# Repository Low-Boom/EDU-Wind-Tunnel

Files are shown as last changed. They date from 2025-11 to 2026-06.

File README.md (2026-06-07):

# Educational Wind Tunnel Controller
**Microcontroller-based PID controller for educational wind tunnel systems**

Developed by [Louis M. Edelman](https://www.researchgate.net/profile/Louis-Edelman) and Olivia Coulon

Debugging assitance provided by Antropic Claude Sonnet 4.5 and verified by humans.

Developed for use with the [Modular Wind Tunnel for STEM Education](https://www.printables.com/@JerrodH) by [Jerrod Hofferth](https://jerrod.hofferth.net/)















---

## Features

### Control & Tuning
- **Full PID Control** (Proportional, Integral, Derivative)
- **Relay Auto-Tuning** (Åström-Hägglund method)
- **sTune Auto-Tuning** (Inflection Point method - optional advanced tuning)
- **Manual PID Tuning** (direct gain adjustment)
- **PWM Rate Limiting** (smooth motor transitions)

### Sensor Processing
- **Pressure Oversampling** (noise reduction)
- **Configurable Airspeed Averaging** (default 20)
- **Ambient Temperature Compensation** (automatic air density correction)
- **Zero-Offset Calibration** (automatic at startup, manual recalibration at will)
- **Multi-Bus I2C Scanner** (automatic device discovery on all available I2C buses)

### Features in Development (Eventually) 
- Serial free untethered control via Modulino controls and a screen for mobility
- A [Controllino](https://www.controllino.com) PLC-based version for industrial applications and education
- A [Mathworks Simulink](https://www.mathworks.com/products/simulink.html) and [Julia Hub DYAD](https://juliahub.com/products/dyad) compatible controller
- Integrated Lift-Drag Force Balance
- Coursework materials for wind tunnel operation and design

---
## Detailed Documentation

- **[HARDWARE.md](HARDWARE.md)** - Detailed wiring, components, and power supply info
- **[TUNING_GUIDE.md](TUNING_GUIDE.md)** - Advanced PID tuning techniques
---

## Quick Start

### Prerequisites
- Arduino IDE 2.0+ or [VSCode with PlatformIO](https://platformio.org/install/ide?install=vscode) (see Installation notes)
- ESP32-P4 microcontroller board (primary/recommended; see [HARDWARE.md](HARDWARE.md) for all supported boards)
- DFRobot SEN0343 (Fermion LWLP5000) differential pressure sensor (±500 Pa, I2C)
- DFRobot SEN0665 (Fermion BMP585) barometric pressure/temperature sensor (I2C)
- PWM-controlled fan with external power source (e.g.[ AC Infinity CLOUDLINE A8 EC-PWM Motor](https://acinfinity.com/hydroponics-growers/cloudline-a8-quiet-inline-fan-with-speed-controller-8-inch/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) or [Noctua 12V PC Fan](https://www.noctua.at/en/products/nf-a14x25-g2-pwm) as recommended by Jerrod H.)
- Depending on board and fan combination, a [Bi-Directional Logic Level Lifter](https://www.adafruit.com/product/757?srsltid=AfmBOopBWeXgpfL63fDoCPbWWtu07TIO7QVbofNmTDtQ4QkU7BxYeCWk) with at least two channels
---

## Hardware Setup

⚠️ Motor power supply must be separate from the microcontroller! This is 120V AC Power for the AC Infinity Fan or a 12V power supply for the 12V PC Fan (e.g. [Noctua NV-PS1](https://www.noctua.at/en/products/nv-ps1))

See [HARDWARE.md](HARDWARE.md) for detailed wiring diagrams and component specifications.

---

## ⚠️ Safety Warnings

1. **Motor Power**: NEVER power motor from the microcontroller - use separate supply
2. **Mechanical**: Secure all components, keep clear of fan during operation
3. **Testing**: Start with low speeds (2-5 m/s), gradually increase
4. **Emergency**: Type `0` to stop or disconnect motor/fan from power

---

### Installation

1. **Install IDE**
   - **Arduino IDE** (recommended for beginners): Download from https://www.arduino.cc/en/software
   - **VSCode + PlatformIO** (alternative, recommended for advanced users): Install [VSCode](https://code.visualstudio.com/) then add the [PlatformIO IDE extension](https://platformio.org/install/ide?install=vscode). PlatformIO handles board packages and libraries automatically.

2. **Install Board Support** (Arduino IDE only; PlatformIO manages this automatically)
   - Open: Tools → Board → Boards Manager
   - Search: "esp32 by Espressif Systems" and install version **3.x** (required for ESP32-P4)
     - Select "ESP32P4 Dev Module" for ESP32-P4 boards (e.g. [Waveshare ESP32-P4-WiFi6-Touch-LCD-7B](https://www.waveshare.com/product/arduino/boards-kits/esp32-p4/esp32-p4-wifi6-touch-lcd-7b.htm))
     - M5 Atom users: version 2.0+ is sufficient; additionally install the [M5Stack board package](https://docs.m5stack.com/en/arduino/arduino_board) or select a generic ESP32 board and configure `PlatformConfig.h` manually
   - For Arduino/Mbed boards: search for the appropriate Mbed OS board package (e.g. "Arduino Mbed OS Giga Boards")

3. **Install Required Libraries**
   - Open: Tools → Manage Libraries
   - Install:
     - `DFRobot_BMP58X` (for DFRobot SEN0665 barometer) — also requires `DFRobot_RTU`
     - `DFRobot_LWLP` (for DFRobot SEN0343 differential pressure sensor)
     - QuickPID
     - **sTune** (optional - for advanced PID autotuning)

4. **Upload Code**
   - Open `EDU-Wind-Tunnel.ino`
   - Select Board: "ESP32P4 Dev Module" (or your specific board)
   - Select Port: Your board's COM port
   - Click Upload

5. **Open Serial Monitor**
   - Set baud rate: **115200**
   - Watch initialization messages to confirm successful hardware setup. 

6. **Allow for Initial Calibration"
   - Once the fan is under control, it will ramp down to 0.
   - A default wait time of 30 seconds is set to allow for the airflow in the tunnel to fully stop
   - 50 Samples are taken from the airspeed sensor to establish a zero offset.
   - This routine can be re-run via the `recal` serial command later

---

## Quick Command Reference

| Command | Description | Example |
|---|---|---|
| `<number>` | Set target airspeed | `10` |
| `tune` | Auto-tune (auto PWM) | `tune` |
| `tune <L> <H>` | Auto-tune (manual PWM) | `tune 40 100` |
| `tune <Kp> <Ki> <Kd>` | Manual PID | `tune 20 8 12` |
| `stune` | sTune auto-tune (advanced) | `stune` |
| `recal` | Recalibrate sensor | `recal` |
| `recal <N>` | Recalibrate (N samples) | `recal 100` |
| `avg <N>` | Set averaging | `avg 10` |

## User-configurable variables (runtime & compile-time) 

### Runtime Commands (via serial)
- Direct setpoint: type a number (m/s) to set target.
- `avg <N>`  
  - Purpose: set pressure averaging samples (1–50). Default 20.  
  - Effect: lower → faster but noisier; higher → smoother but more lag.  
  - Typical: `avg 3` for fast tuning, `avg 15–30` for stable operation.

- `tune` / `tune <low> <high>` / `tune <Kp> <Ki> <Kd>`  
  - `tune` : auto-estimate PWM band and run relay tuning.  
  - `tune <low> <high>` : force PWM range (manual). Use when auto-estimate is poor.  
  - `tune <Kp> <Ki> <Kd>` : manually apply PID gains; controller resets automatically.

- `stune` (requires sTune library)
  - Advanced autotuning using inflection point method
  - More stable and predictable than relay tuning
  - Automatically determines step size and monitors system response
  - Default: "No Overshoot" tuning for stable operation
  - Usage: Set target airspeed (min 2 m/s), then type `stune`
  - Duration: ~30-60 seconds depending on system response
  - **Tuning method can be changed** at compile-time (see below)

### Compile-time (edit `EDU-Wind-Tunnel.ino`)
Open the sketch and edit the configuration block near the top:

- **`PlatformConfig.h`** – controls all board-specific pin defaults.  Edit this
  file if your wiring differs from the defaults:
  - M5 Atom Stack: `DEFAULT_PWM_PIN 19`, `DEFAULT_TACH_PIN 23`, I2C on GPIO 26/32 (Grove)
  - Generic ESP32-S3: `DEFAULT_PWM_PIN 10`, `DEFAULT_TACH_PIN 11`, I2C on GPIO 8/9
  - ESP32-P4 (Waveshare): `DEFAULT_PWM_PIN 6`, `DEFAULT_TACH_PIN 5`, I2C on GPIO 7/8
  - Generic ESP32: `DEFAULT_PWM_PIN 9`, `DEFAULT_TACH_PIN 2`, I2C on GPIO 21/22
  - Classic Arduino: `DEFAULT_PWM_PIN 9`, `DEFAULT_TACH_PIN 2` (board defaults)

- `const sTune::TuningMethod STUNE_METHOD = sTune::NoOvershoot_PID;`
  - Selects the sTune tuning method (default: NoOvershoot_PID for stability)
  - Available options:
    - `sTune::ZN_PID` - Ziegler-Nichols (moderate overshoot, fast response)
    - `sTune::DampedOsc_PID` - Damped Oscillation (balanced)
    - `sTune::NoOvershoot_PID` - No Overshoot (conservative, stable) **[DEFAULT]**
    - `sTune::CohenCoon_PID` - Cohen-Coon (good for systems with delay)
    - `sTune::Mixed_PID` - Mixed (average of all methods)
  - For PI control instead of PID: use ZN_PI, DampedOsc_PI, NoOvershoot_PI, etc.

- `const int PRESSURE_OVERSAMPLES = 5;`  
  - Oversampling per measurement (3–8 typical).

- `int pressureAverageSamples = 20;`  
  - Averaging window for measurements (1–50). Effective lag ≈ updateInterval × pressureAverageSamples.

- `const unsigned long updateInterval = 200;`  
  - Main loop period in ms (default 200 ms). If changed, QuickPID sample time will be set from this.

- `int calibrationSamples = 50;`  
  - Samples used for zero-offset calibration at startup/recal.

- `const float MAX_AIRSPEED = 28.0;`  
  - Upper bound for setpoints; change if your tunnel differs.

- `const float MAX_PWM_CHANGE_PER_CYCLE = 25.0;`  
  - PWM slew limit per update cycle; set to 255 to disable.

- `float relayHysteresis = 0.5;`  
  - m/s hysteresis for relay auto-tune to prevent chattering.

- `const int PWM_pin = 9;` and `const int TACH_pin = 2;`  
  - Pin assignments; change if wiring differs.

- `const float MIN_TUNE_SETPOINT = 2.0;` and `const int REQUIRED_CYCLES = 3;`  
  - Minimum auto-tune setpoint and cycles needed for a valid tune.

Data output format
These can be quickly plotted using the Arduino IDE Serial Plotter or logged for later processing in a .csv format.
Example line printed periodically:
```
123s | V:10.23 | T:10.00 | PWM:127 | P:61.45 | T:24.5°C | Err:-0.23

elapsed time | airspeed (m/s) | target (m/s) | PWM (0–255) | differential pressure (Pa) | ambient temp (°C) | error (m/s)
```
---

## Serial Control from Android

Once the sketch is compiled and uploaded, it can be controlled via a USB connection to an Android phone using the excellent [Serial USB Terminal App by Kair Morichi](https://www.kai-morich.de/android/).

1. Connect via a USB cable with whatever adapters or USB-C hubs are required for your particular phone and board.

2. Set the Baud Rate to 115200 and operate as you would from the Arduino IDE

3. It is recommended that you set macros in the app according to the Quick Command Reference table above.

---

## I2C Device Scanner

The system includes an automatic I2C device scanner that runs at startup to help verify sensor connections. The scanner automatically detects and scans all available I2C buses on your board:

- **ESP32 / ESP32-S3 / ESP32-P4 / ESP32-PICO (M5 Atom)**: Scans Wire only; Wire is initialised with the SDA/SCL pins defined in `PlatformConfig.h`
- **Classic Arduino (Uno, Nano, Mega)**: Scans Wire only
- **Arduino Uno Rev4**: Scans Wire and Wire1
- **Modern Boards (RP2040, SAMD21/51)**: Scans Wire and Wire1
- **Arduino GIGA R1**: Scans Wire, Wire1, and Wire2

### Expected Output

On successful startup, you should see:
```
[I2C] Multi-Bus Scanner
=====================================
Available I2C buses: 2
Scanning I2C bus Wire
 - Found device at 0x47
 - Total devices found on Wire: 1

Scanning I2C bus Wire1
 - No I2C devices found on Wire1

[I2C] Scan complete
=====================================
```

The DFRobot SEN0665 (BMP585) barometer should appear at address `0x47` (or `0x46` if the address jumper is changed).
The DFRobot SEN0343 (LWLP5000) differential pressure sensor uses I2C address `0x00` (a fixed hardware address) and will **not** appear in the bus scan — it is initialised directly and its absence from the scan is expected and normal.

If the BMP585 is not found, check:
- I2C wiring (SDA/SCL connections)
- Device power supply (3.3 V)
- Pull-up resistors (typically built into breakout boards)

---

## 📄 License
Derived from the Modular Wind Tunnel for STEM Education by Jerrod H. under a Creative Commons4.0 License

This project uses open-source libraries:
- QuickPID (MIT License)
- DFRobot_BMP58X (MIT License) — for DFRobot SEN0665 (BMP585 barometer)
- DFRobot_LWLP (MIT License) — for DFRobot SEN0343 (LWLP5000 differential pressure sensor)
- sTune (MIT License) - Optional advanced autotuning library by David Lloyd

See individual library licenses for details.

---

## Support
This code is provided with no warranty or expectation of support. If you post something in the issues or discussion sections of GitHub I or another community member may be able to resolve your question. 
This is an initial release so the documentation and best practices are still evolving. If you have contributions, please fork, tweak, pull, and merge at your discretion.

- **Issues**: [GitHub Issues](https://github.com/Low-Boom/EDU-wind-tunnel/issues)
- **Discussions**: [GitHub Discussions](https://github.com/Low-Boom/EDU-wind-tunnel/discussions)

---

## Acknowledgments
- Jerrod H. for the Wind Tunnel Design
- QuickPID Library by Dlloydev
- sTune Library by Dlloydev
- DFRobot for the BMP58X (SEN0665) and LWLP (SEN0343) sensor libraries
- Arduino and Espressif communities for board and library support

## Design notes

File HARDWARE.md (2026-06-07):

# Hardware Configuration Guide

## Hardware Modifications to Educational Wind Tunnel
A static pressure ring must be added at the inlet of the test section to measure airspeed.
An updatead version of the test section or an additional component between the inlet and test section are included for this purpose. Get them from [Printables](https://www.printables.com/model/1480487-airspeed-static-pressure-ring-modification-for-edu).

## Required Components

- A compatible microcontroller
	- **ESP32-P4 (Recommended)**
   		- [Waveshare ESP32-P4-WiFi6-Touch-LCD-7B](https://www.waveshare.com/product/arduino/boards-kits/esp32-p4/esp32-p4-wifi6-touch-lcd-7b.htm), [M5Stack Tab5 P4 Board](https://shop.m5stack.com/products/m5stack-tab5-iot-development-kit-esp32-p4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), or other ESP32-P4 dev-boards
	          - Dual-core RISC-V; WiFi 6 via on-board ESP32-C6 companion chip; requires ESP32 Arduino core 3.x
	- Other supported ESP32 boards
	     - [M5 Atom Lite / M5 Atom Stack (ESP32-PICO-D4)](https://shop.m5stack.com/products/atom-lite-esp32-development-kit)  (requires ESP32 Arduino core 2.0+)
	          - Compact form-factor; sensors attach to the Grove/HY2.0 bottom connector
	     - Generic ESP32-S3 dev-boards  (requires ESP32 Arduino core 2.0+)
	     - Any generic ESP32 board (WROOM, WROVER, etc.)
	- Arduino or Arduino Compatible MBED microcontroller (alternative/legacy)
	     - [Arduino Uno Rev. 4](https://store-usa.arduino.cc/pages/uno-r4?srsltid=AfmBOorOs0ix30CZM4vLKSA9m6F7qrPhlblCfdp3-wQMstfBhTvr8o13)
	     - [Arduino Mega 2560 Rev. 3](https://store-usa.arduino.cc/products/arduino-mega-2560-rev3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)
	     - [Arduino Giga R1/R1 Wifi](https://store-usa.arduino.cc/products/giga-r1-wifi?queryID=a518cc78eda98ff33faf6b976f3d470a)
- [3D Printed Educational Wind Tunnel with Static Pressure Ring](https://www.printables.com/model/1480487-airspeed-static-pressure-ring-modification-for-edu) Modification
- [Static Pressure Manifold](https://www.printables.com/model/1480487-airspeed-static-pressure-ring-modification-for-edu)
     - 3D Printed Manifold for 4x 0.063in (1/16in) to 1x 0..125in (1/8in) tubing
     - [Scanivalve Pneumatic Manifolds](https://scanivalve.com/products/pneumatic-connectors-and-tubing/pneumatic-manifolds/)
- DFRobot SEN0343 (Fermion LWLP5000) differential pressure sensor (±500 Pa, I2C address 0x00)
- DFRobot SEN0665 (Fermion BMP585) barometric sensor (I2C address 0x47, alt 0x46)
- PWM-capable motor or fan
     - For Standard 140 mm Wind Tunnel: [Noctua NF-A12x25 G2 PWM](https://www.noctua.at/en/products/nf-a12x25-g2-pwm) with a Noctua [NV-PS1](https://www.noctua.at/en/products/nv-ps1) or [NV-SPH1](https://www.noctua.at/en/products/nv-sph1) Power Supply or similar with the 
     - For Larger 8in/200mm Fann Driven Tunnel: [AC Infinity CLOUDLINE A8, Quiet Inline Fan with Speed Controller](https://acinfinity.com/hydroponics-growers/cloudline-a8-quiet-inline-fan-with-speed-controller-8-inch/)
          - Note DO NOT get the "smart" version. The standard PWM speed controller version is needed here.
          - The now depracated but still available [AC Infinity CLOUDLINE S8 Pro](https://a.co/d/iekl0lr) is an equivalent option
- Four Pin PWM Fan Cable such as the [Noctua NA-SEC1](https://www.noctua.at/en/products/na-sec1)
- 1/16 in (0.063in) OD steel tubing for static pressure taps
     - [McMaster 304 Stainless Steel Tubing Miniature, 0.065" OD, 0.009" Wall Thickness](https://www.mcmaster.com/5560K73-5560K731/)
     - [063 Scanivalve Stainless Steel Tubulations](https://scanivalve.com/products/pneumatic-connectors-and-tubing/stainless-steel-tubulations/)
     - [Amazon 304 Stainless Steel Capillary Tube, OD 1.5mm](https://a.co/d/c9E1Kos)
- 1/16in (0.063in) ID soft line silicone or polyurethane/Tygon tubing
     - [Scanivalve 063 Plastic Tubing](https://scanivalve.com/products/pneumatic-connectors-and-tubing/plastic-tubing/)
     - [Amazon 1/16" ID Silicone Tubing, Food Grade 1/16" ID x 1/8" OD 10 Feet Length Pure Silicone Hoses](https://a.co/d/4P2acrw)
- 1/8in (0.125in) ID soft line silicone or polyurethane/Tygon tubing
     - [Scanivalve 125 Plastic Tubing](https://scanivalve.com/products/pneumatic-connectors-and-tubing/plastic-tubing/)
     - [Amazon 1/8" ID Silicone Tubing, Food Grade 1/8" ID x 3/16" OD 10 Feet Length Pure Silicone](https://a.co/d/5y4ox0C)
- Assorted STEMMA QT/Qwiic 4-pin I2C Cabling. At least three (3) QT to QT and one QT to Female Dupont Sockets are recommended. Extras are always a good idea
     - [Adafruit Qwiic Cabling](https://www.adafruit.com/product/4399)
     - [Amazon I2C Qwiic Cable Kit Assortment](https://a.co/d/anmSIUS)
- One STEMA QT/Qwiic to JST-GH Adapter for the airspeed sensor
     - You can make one yourself by splicing the airspeed sensors included cable with a Qwiic
     - [Aamazon GH Connector to Dupont 2.54 Adapter Kit](https://a.co/d/dRP7Vl2)

---

## ESP32 Pin Mapping

All ESP32 pin defaults are set in `EDU-Wind-Tunnel/PlatformConfig.h`.
Edit that file if your wiring differs.

### ESP32-P4 (e.g. Waveshare ESP32-P4-WiFi6-Touch-LCD-7B) — Recommended

| Function | GPIO | Notes |
|---|---|---|
| Serial | USB  | 115200 baud via USB |
| PWM output | 6  | Use GPIOs ≤ 36 (change as needed) |
| Tachometer | 5  | Use GPIOs ≤ 36 (change as needed) |
| I2C SDA | 7  | ESP32-P4 default |
| I2C SCL | 8  | ESP32-P4 default |

> **ESP32-P4 notes** – The ESP32-P4 is a dual-core RISC-V chip without built-in
> WiFi/BT; the Waveshare board pairs it with an ESP32-C6 for WiFi 6.  GPIOs 14-19
> are reserved for the SDIO host interface to that companion chip — do not
> reassign them.  Use GPIOs ≤ 36 to avoid LDO power issues on higher-numbered
> pins.  Requires ESP32 Arduino core **3.x** (select "ESP32P4 Dev Module" in the
> board manager).

### M5 Atom Stack / M5 Atom Lite (ESP32-PICO-D4)

| Function | GPIO | Notes |
|---|---|---|
| Serial | USB  | 115200 baud via USB-C |
| PWM output |  19  | HAT header or breadboard (change as needed) |
| Tachometer |  23  | HAT header or breadboard (change as needed) |
| I2C SDA |  26  | Grove / HY2.0 bottom connector |
| I2C SCL |  32  | Grove / HY2.0 bottom connector |

> **Note** – Both the DFRobot SEN0665 (BMP585) barometer and the DFRobot SEN0343
> (LWLP5000) differential pressure sensor operate at 3.3 V and are compatible
> with the Grove connector's 3.3 V power rail.

### Generic ESP32-S3

| Function | GPIO | Notes |
|---|---|---|
| Serial | USB  | 115200 baud via USB |
| PWM output |  10  | Any PWM-capable GPIO (change as needed) |
| Tachometer |  11  | Any interrupt-capable GPIO (change as needed) |
| I2C SDA | 8  | Standard ESP32-S3 dev-board default |
| I2C SCL | 9  | Standard ESP32-S3 dev-board default |

### Generic ESP32

| Function | GPIO | Notes |
|---|---|---|
| Serial | USB  | 115200 baud |
| PWM output | 9  | Any PWM-capable GPIO |
| Tachometer | 2  | Any interrupt-capable GPIO |
| I2C SDA |  21  | Standard ESP32 default |
| I2C SCL |  22  | Standard ESP32 default |

> **PWM note** – `analogWrite()` on ESP32 (core 2.x+) generates ~1 kHz PWM at
> 8-bit resolution (0–255), which should be compatible with most fans.  Fans that
> strictly require a 25 kHz signal may need an additional LEDC configuration
> (see Arduino ESP32 `ledcWrite` documentation).

## Arduino / Mbed Pin Mapping (alternative/legacy boards)

- Serial: USB / Serial Monitor at 115200 baud
- PWM output: Arduino digital pin 9 → PWM signal input
- PWM Tachometer input: Arduino digital pin 2 (optional)
- I2C: SDA / SCL → BMP585 (SEN0665) and LWLP5000 (SEN0343)
     - Automatic I2C bus detection for BMP585 (e.g. Wire, Wire1, Wire2).
     - LWLP5000 always uses the primary Wire bus (I2C address 0x00 is fixed).
     - Sensors can be used on the same or different buses
	- BMP585 Barometer supports 3.3V power.
	- LWLP5000 Differential Pressure Sensor supports 3.3V power.
 	- See I2C section below for more detail on wiring configuration alternatives

## If Using the AC Infinity PWM Fans (Skip if Using 12V PC Fan)

AC Infinity uses an industrial 10V PWM standard while most microcontroller boards output 3.3V or 5V PWM logic. You will need to interpose a bi-directional level logic shifter to ensure the AC Infinity blower runs at full performance.

The [Adafruit 4-channel Bi-Directional Logic Level Converter - BS138](https://www.adafruit.com/product/757) is recommended for this. For more information on PWM wiring standards, read the [PWM White Paper by Noctua](https://cdn.noctua.at/media/Noctua_PWM_specifications_white_paper.pdf).

Note that many third-party Arduino-based boards have different Vin limits than first-party Arudino boards. For example, Adafruit Metro boards max out at 9V. As such, do not power the microcontroller directly from the fan unless you know your particular board can handle 10 Vin. Skip the 10V power connections and use USB power for such boards.

The wiring configration for control logic and sensors for the Arduino Mega 2560, Giga R1, and Uno R4 with an AC Infinity fan are diagramed below. 

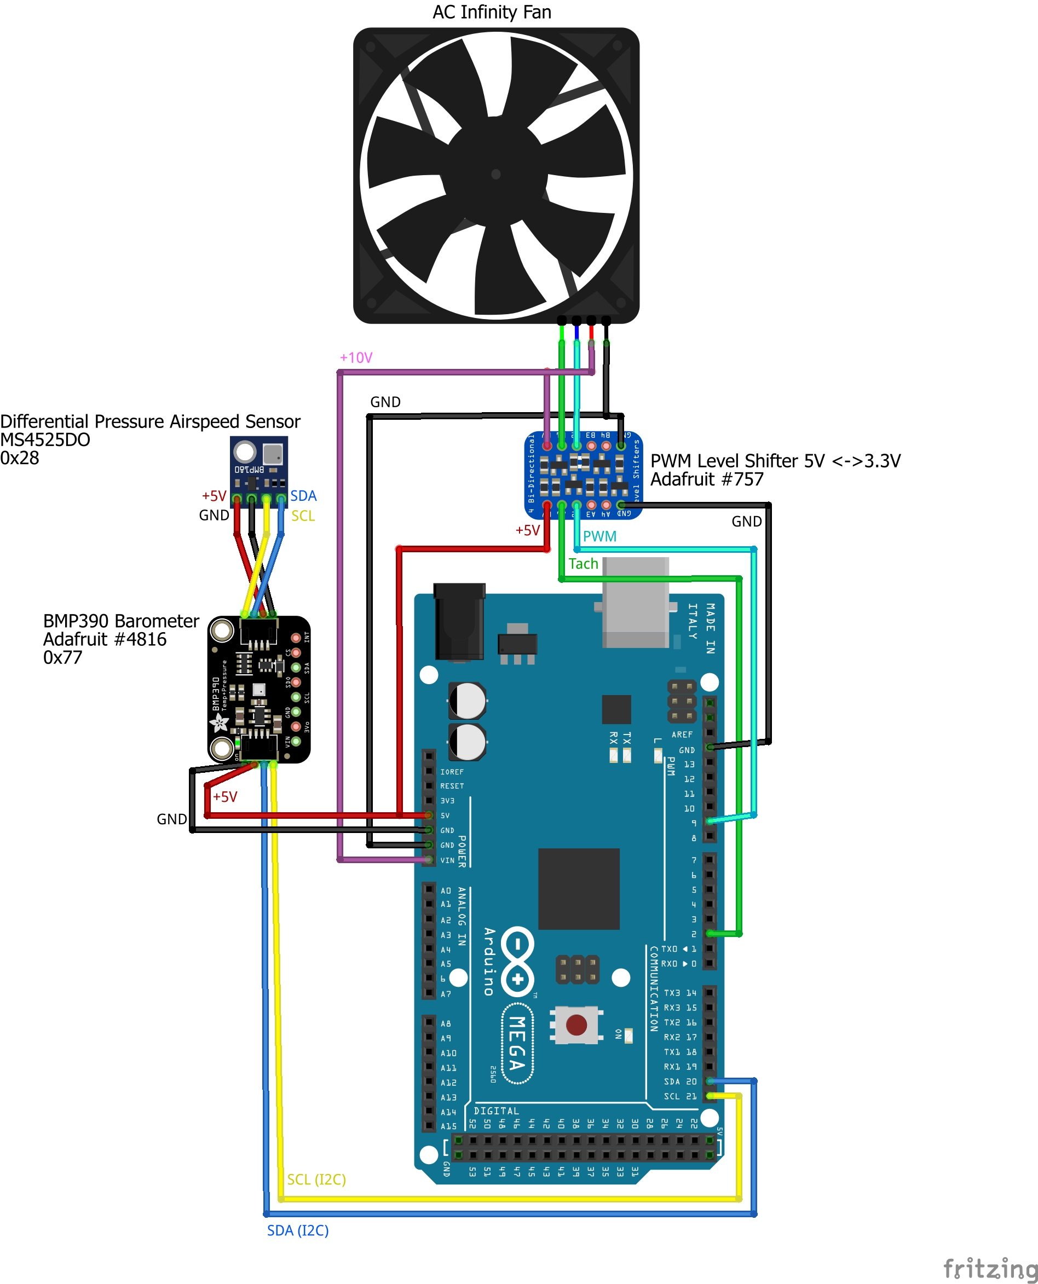
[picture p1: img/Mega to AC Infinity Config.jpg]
Arduino Mega 2560 and AC Infinity Fan Wiring Configration
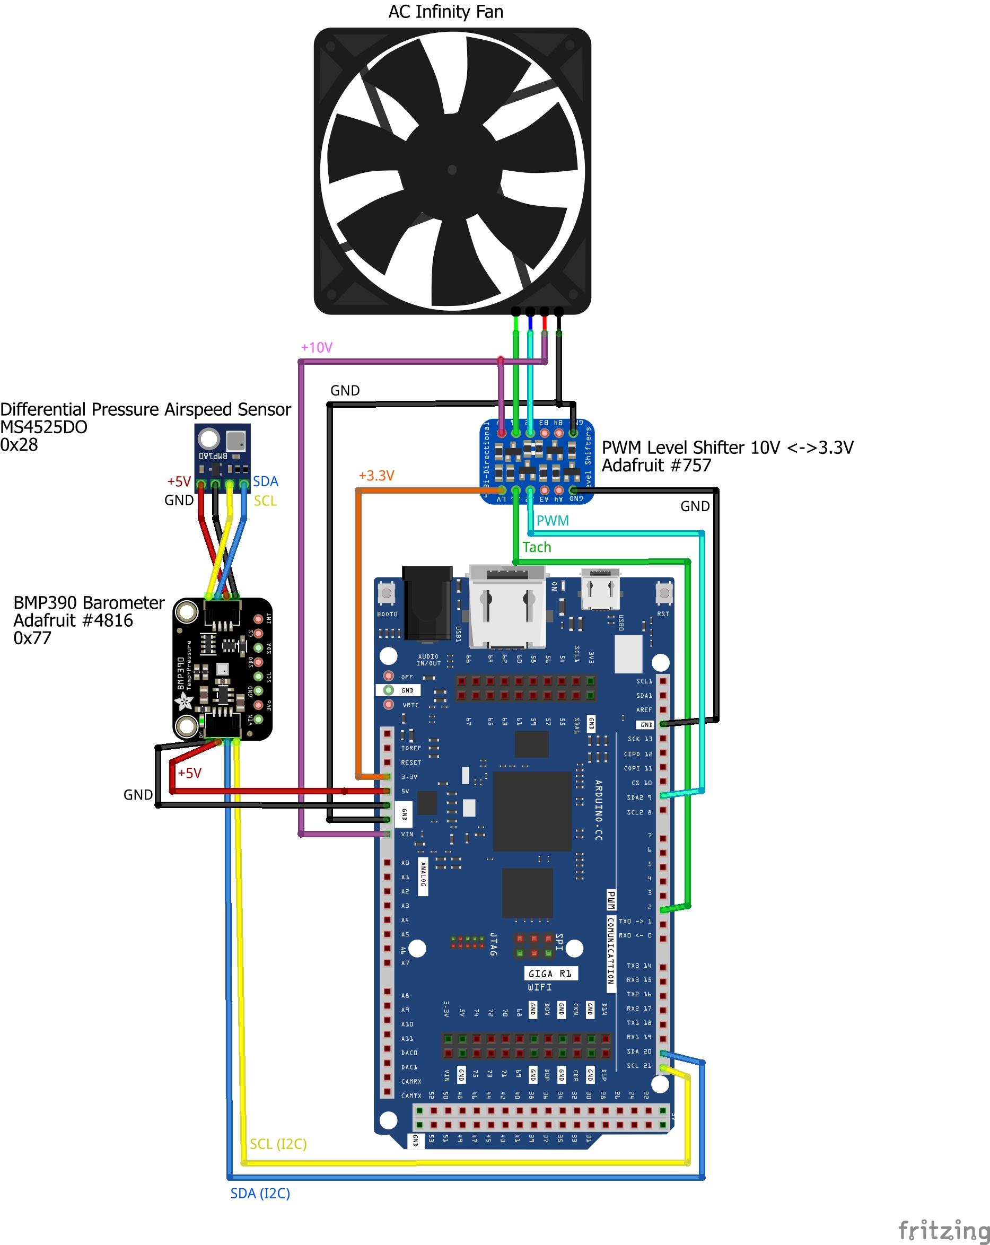
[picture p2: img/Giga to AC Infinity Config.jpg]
Arduino Giga R1 and AC Infinity Fan Wiring Configration
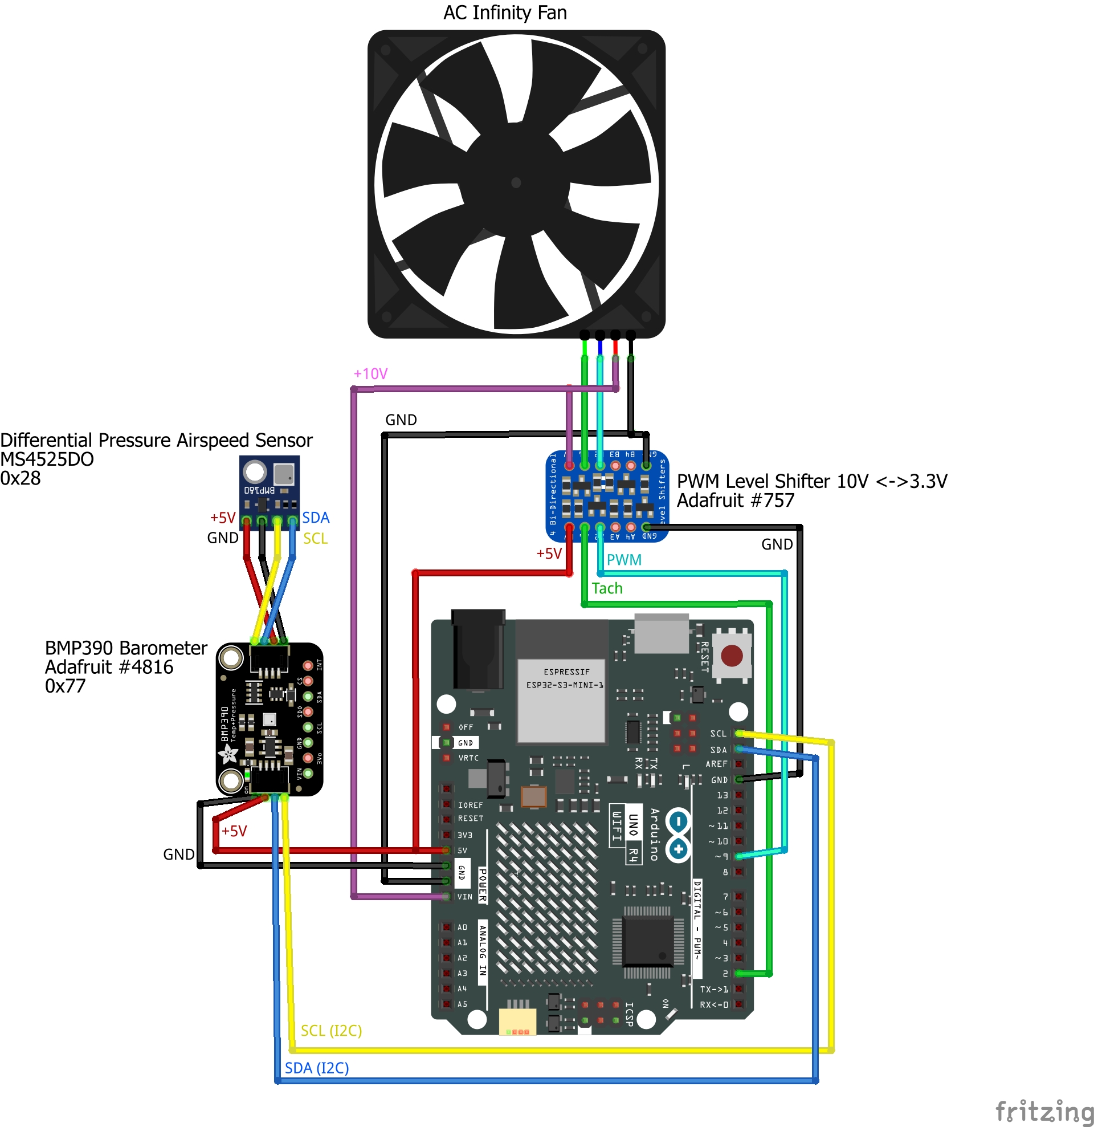
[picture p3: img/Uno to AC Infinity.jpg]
Arduino Uno R4 and AC Infinity Fan Wiring Configration
 

Additionally. You should wire a standard 4-pin fan connector, such as the [Noctua NA-SEC1](https://www.noctua.at/en/products/na-sec1), in place of the AC Infinity UIS USB-C(ish) connector. Connect a corresponding female 4-pin connector to your logic level board. These can be created quickly using a single 4-pin fan extension cabling and a little crimping.

Unscrew the four self tapping screws that secure hatch on the side of the AC Infinity fan to reveal the wiring terminal block. Wire it as noted in the image below. TAC is the fan tachometer feedback, PWM is the control signal. 

> Note: Some newer AC Infinity models seem to have removed the terminal block pictured however wire color coding appears to be identical. It is recommended that you add in your own terminal block for convenience.
     
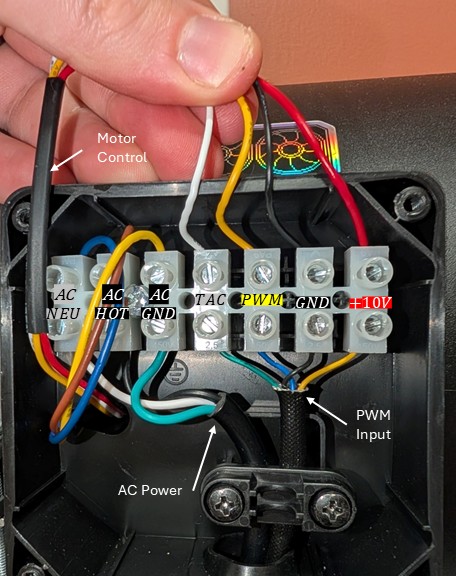
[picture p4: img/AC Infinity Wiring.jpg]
AC Infinity Terminal Block Wiring
 

## If Using a 12V PC Fan (Skip if Using AC Infinity Fan)

PC fans use the 5V PWM standard as outlined in the [PWM White Paper by Noctua](https://cdn.noctua.at/media/Noctua_PWM_specifications_white_paper.pdf). Most ESP32 boards output 3.3V logic, so you will need to interpose a bi-directional level logic shifter to ensure full performance.

The [Adafruit 4-channel Bi-Directional Logic Level Converter - BS138](https://www.adafruit.com/product/757) is recommended for this.

The wiring configration for control logic and sensors for the Arduino Mega 2560, Giga R1, and Uno R4 with an externally powered 12V PC Fan are diagramed below.

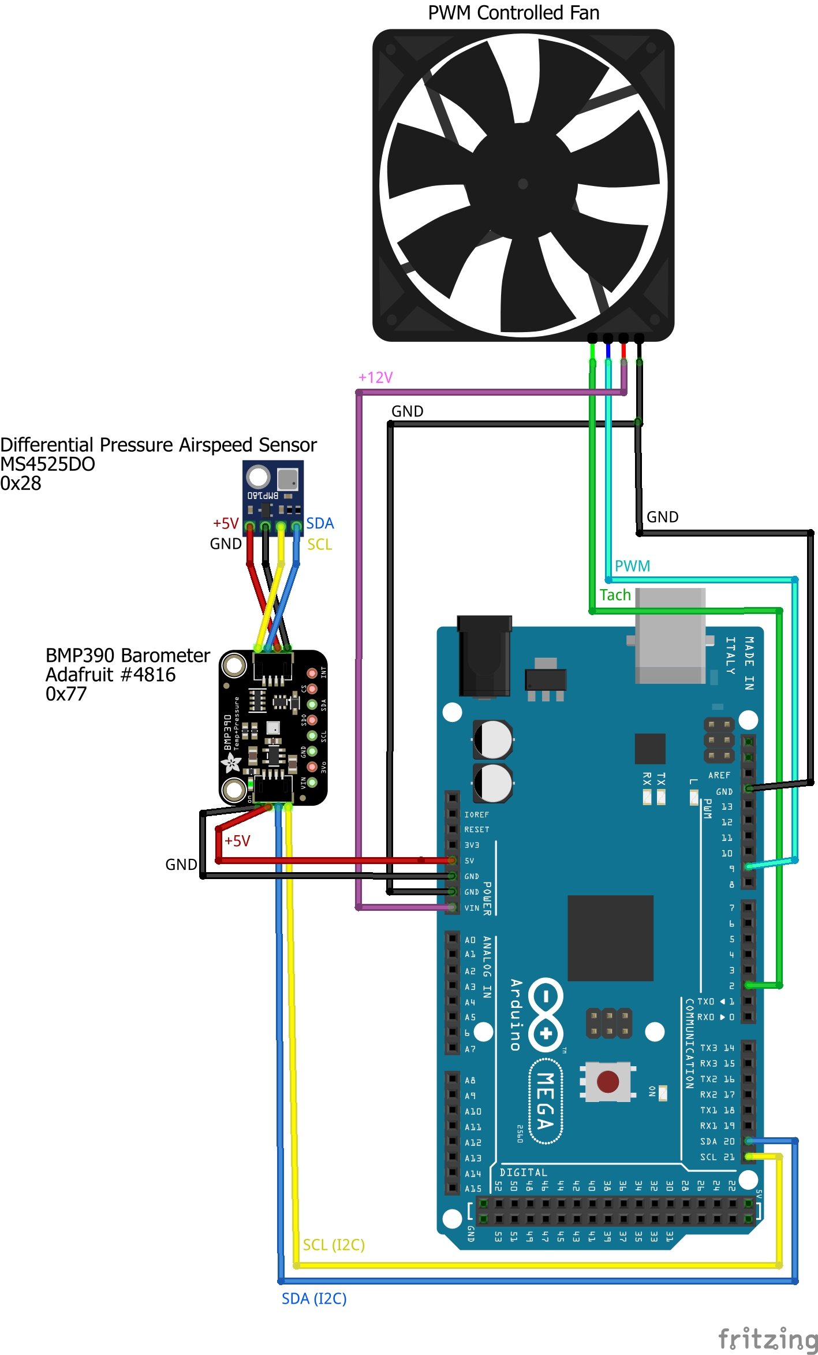
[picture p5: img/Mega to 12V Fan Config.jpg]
Arduino Mega 2560 and 12V Fan Wiring Configration
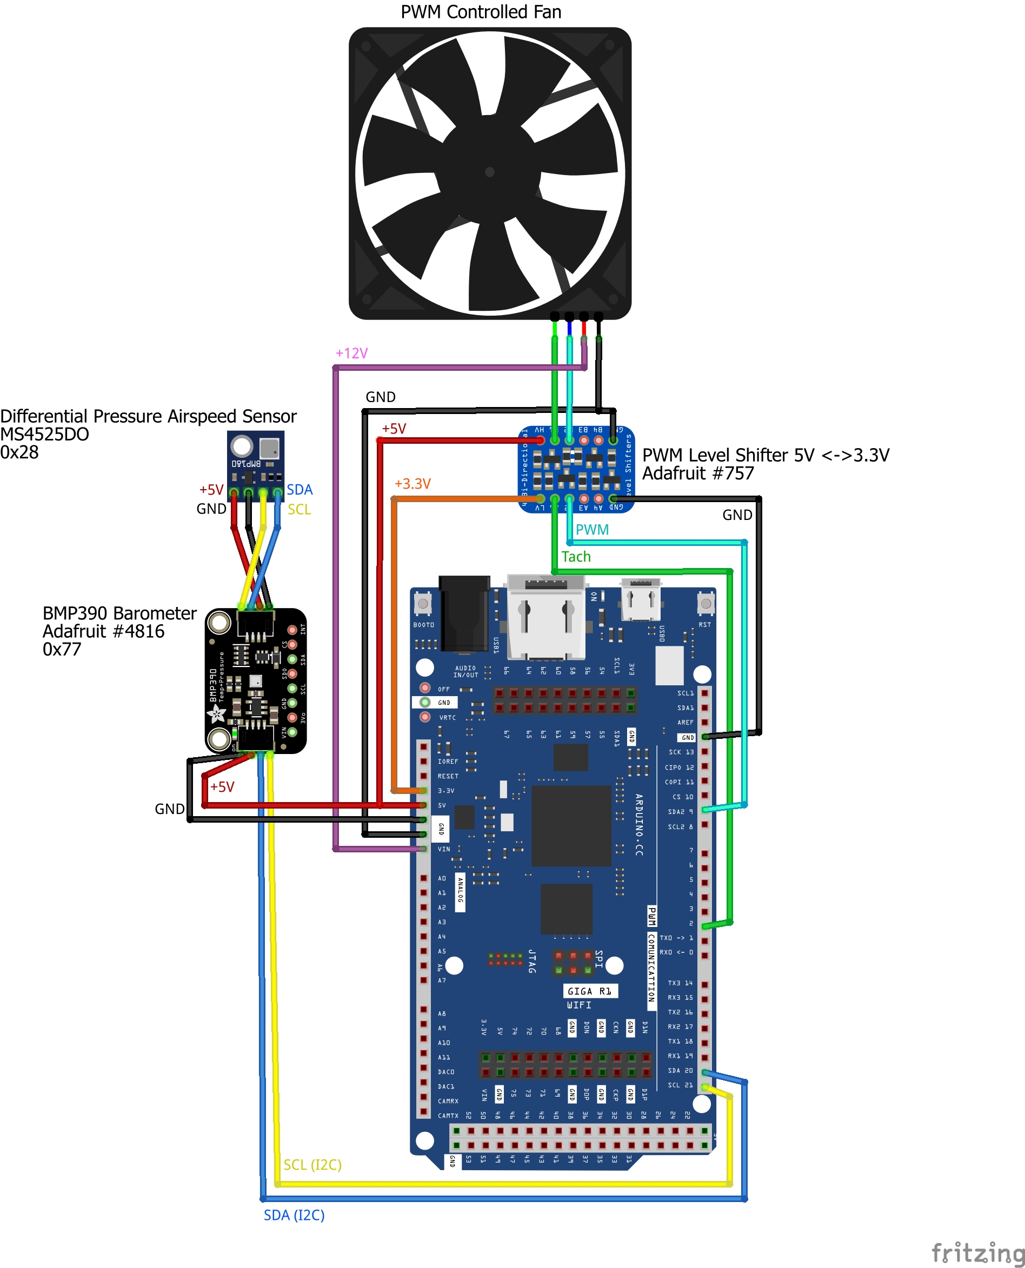
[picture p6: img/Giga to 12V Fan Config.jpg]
Arduino Giga R1 and 12V Fan Wiring Configration
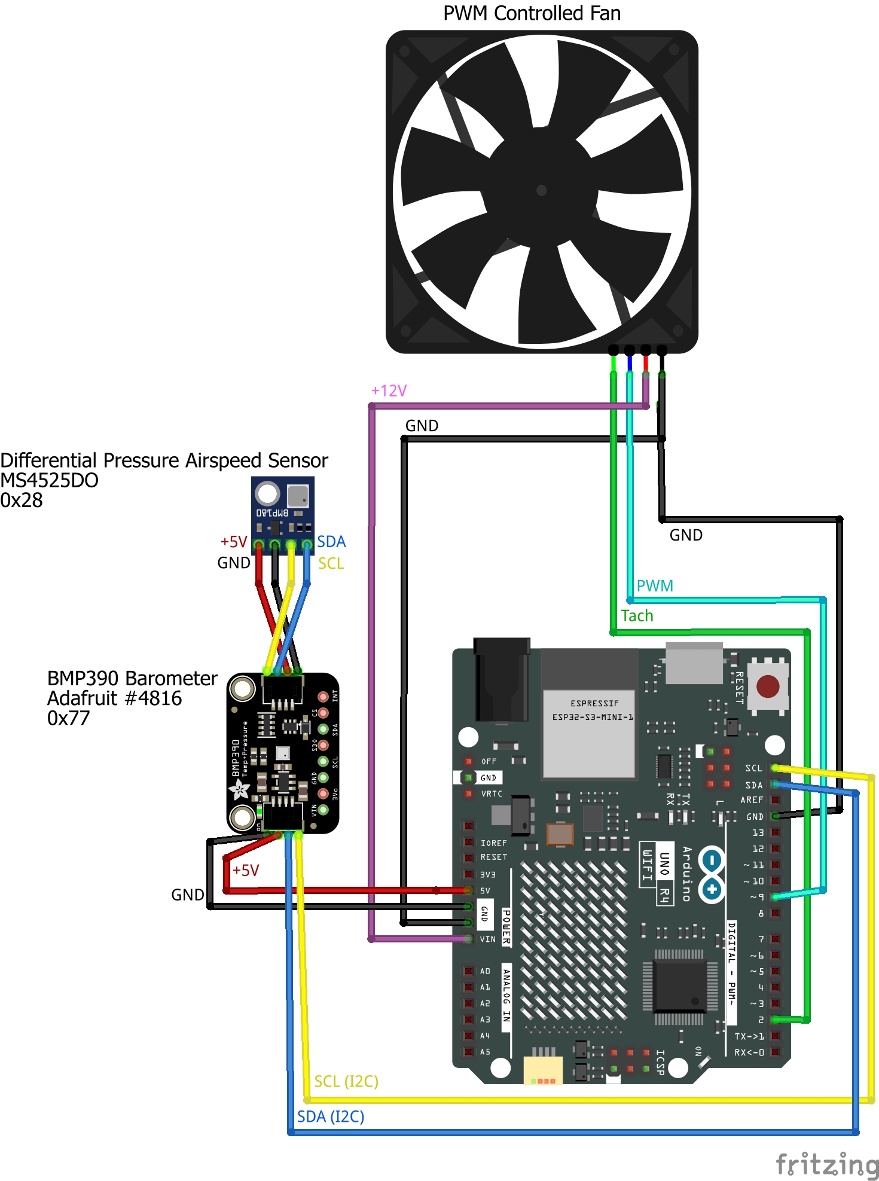
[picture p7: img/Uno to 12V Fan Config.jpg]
Arduino Uno R4 and 12V Fan Wiring Configration
  

## I2C Wiring and Power Permutations

Both sensors — the DFRobot SEN0343 (LWLP5000) differential pressure sensor and the DFRobot SEN0665 (BMP585) barometer — operate at 3.3 V and are fully compatible with the Qwiic/STEMMA QT I2C wiring standard. The BMP585 is discovered automatically by the I2C bus scanner; the LWLP5000 uses the fixed I2C address `0x00` and is initialised directly on Wire (it will not appear in the bus scan — this is expected). Both sensors can be daisy-chained on the same bus or split across buses.

As of version 1.2, the sketch will automatically determine which bus the BMP585 is on and connect accordingly. Two example configurations for wiring the I2C connections on the Arduino Uno R4 are shown below.

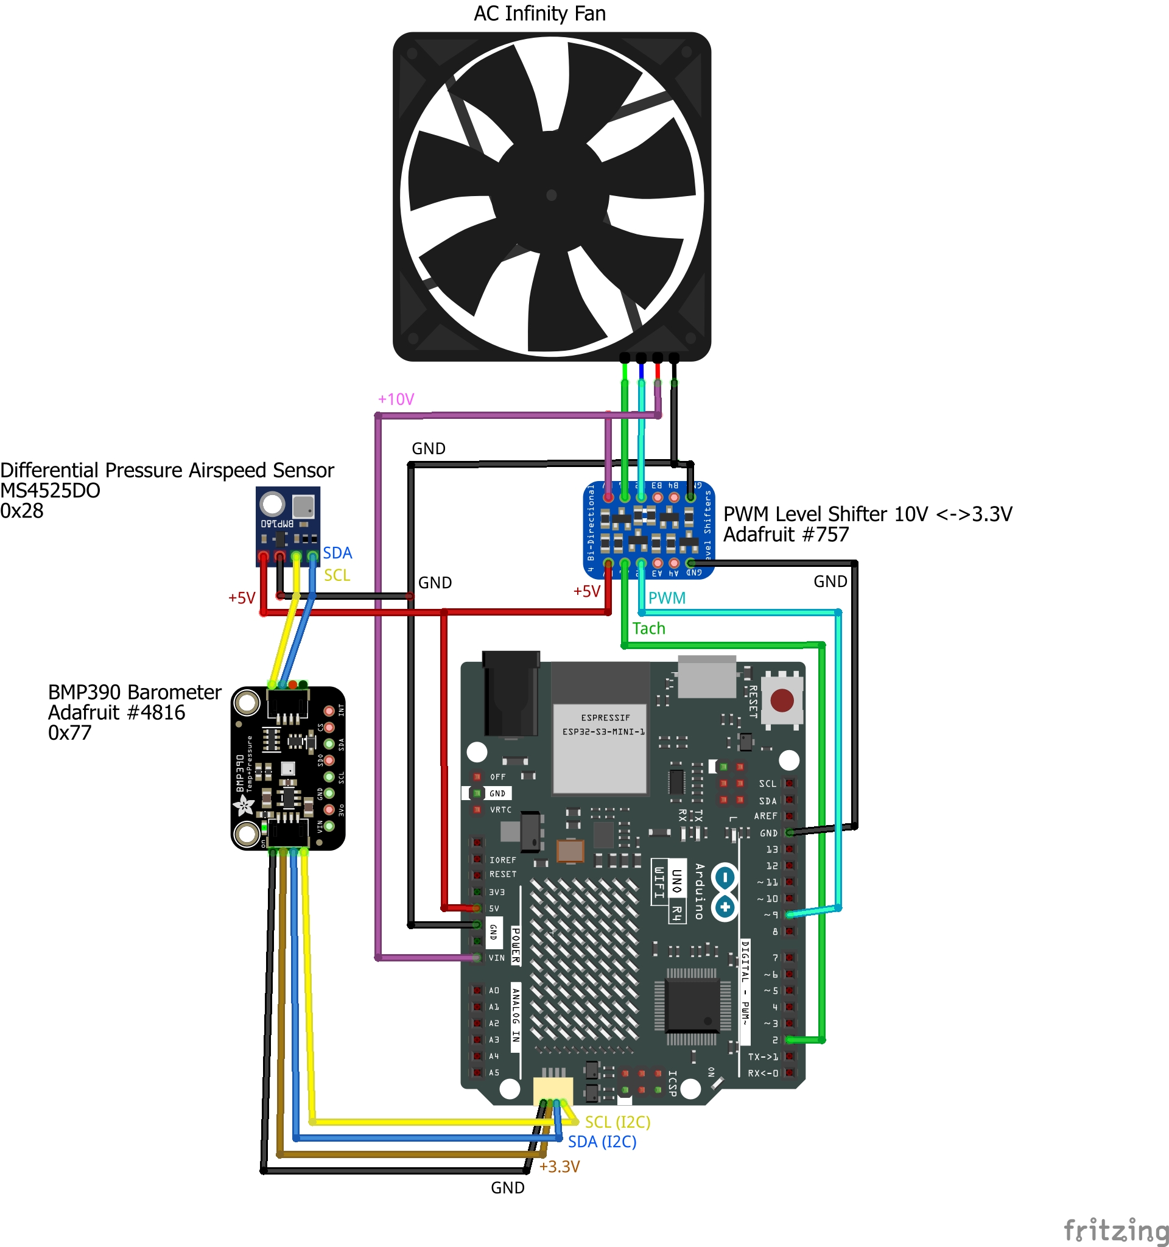
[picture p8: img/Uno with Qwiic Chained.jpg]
Arduino Uno R4 Daisy Chained
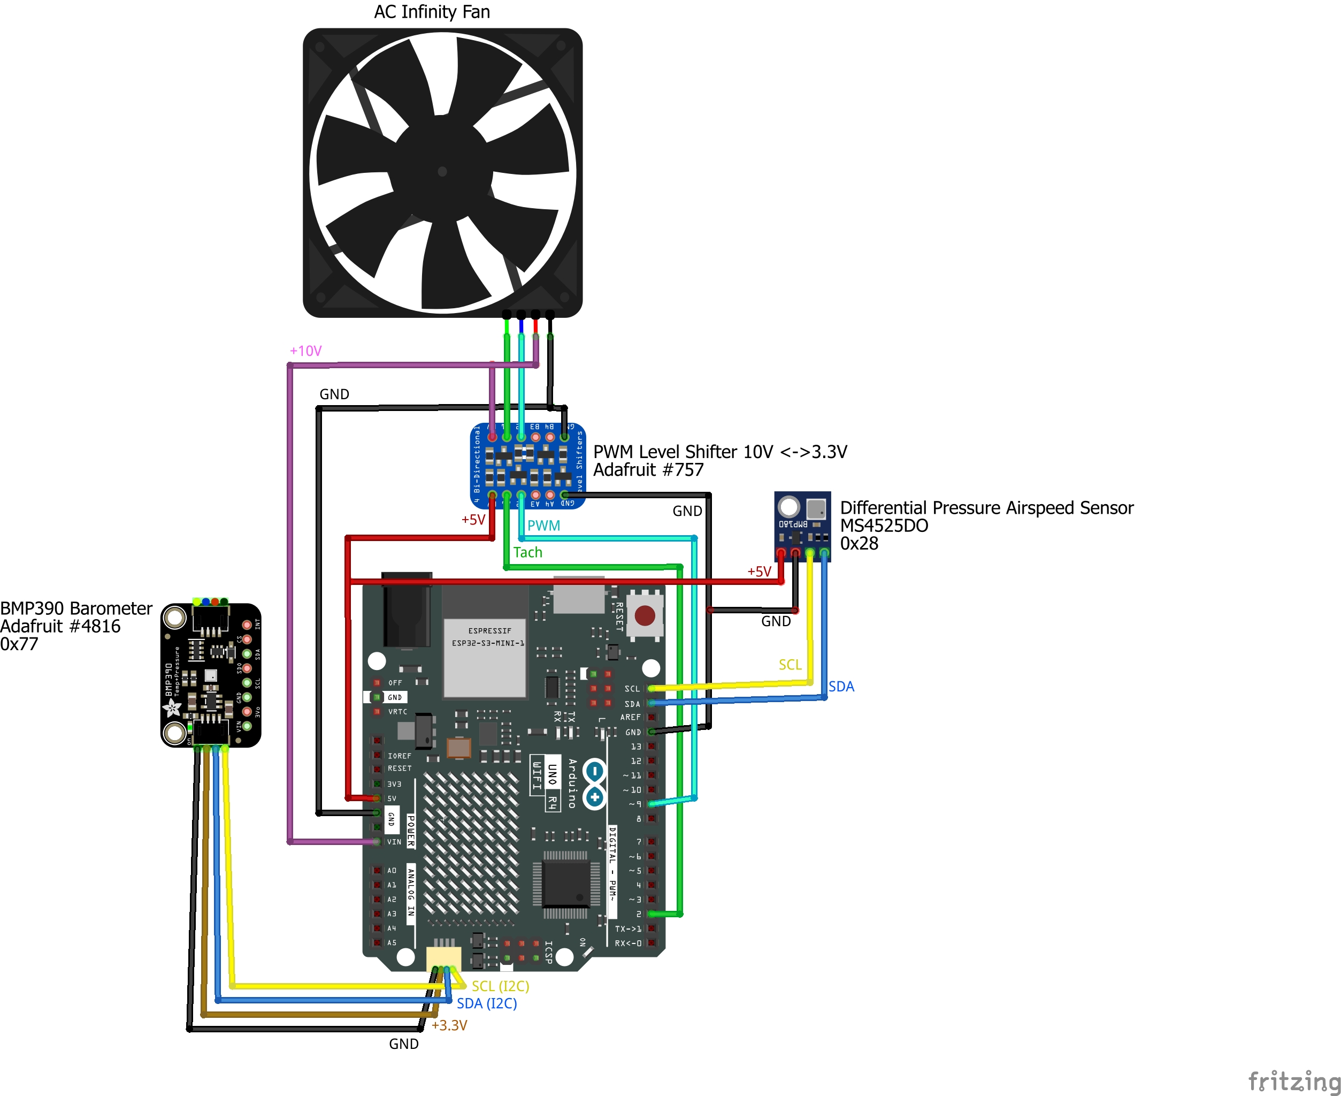
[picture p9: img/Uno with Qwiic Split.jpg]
Arduino Uno R4 Split Bus
 

---

## Airspeed Sensor Plumbing
   - DFRobot SEN0343 (LWLP5000) high-pressure port ← Exposed to atmosphere away from the tunnel inlet or outlet
   - DFRobot SEN0343 (LWLP5000) low-pressure port ← Test section static pressure ring through the manifold
   - Note that the port orientation can vary between manufacturers and batches.
        - Swap the two tubes if you are getting only 0 m/s speed readings.

---

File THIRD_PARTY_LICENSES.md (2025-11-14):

# Third-Party Licenses

This project uses the following third-party libraries and components:

## QuickPID
- **Author**: dlloydev
- **License**: MIT License
- **Repository**: https://github.com/Dlloydev/QuickPID
- **Description**: Fast PID controller library for Arduino

## Adafruit BMP3XX Library
- **Author**: Adafruit Industries
- **License**: BSD License
- **Repository**: https://github.com/adafruit/Adafruit_BMP3XX
- **Description**: Library for BMP3XX barometric pressure and temperature sensors

## Bolder Flight Systems MS4525DO
- **Author**: Bolder Flight Systems
- **License**: MIT License
- **Repository**: https://github.com/bolderflight/ms4525do
- **Description**: Arduino library for MS4525DO differential pressure sensors

## sTune
- **Author**: David Lloyd (Dlloydev)
- **License**: MIT License
- **Repository**: https://github.com/Dlloydev/sTune
- **Description**: Open loop PID autotuner using inflection point test method
- **Copyright**: Copyright (c) 2022 Dlloydev

### sTune Full License Text

```
MIT License

Copyright (c) 2022 Dlloydev

Permission is hereby granted, free of charge, to any person obtaining a copy
of this software and associated documentation files (the "Software"), to deal
in the Software without restriction, including without limitation the rights
to use, copy, modify, merge, publish, distribute, sublicense, and/or sell
copies of the Software, and to permit persons to whom the Software is
furnished to do so, subject to the following conditions:

The above copyright notice and this permission notice shall be included in all
copies or substantial portions of the Software.

THE SOFTWARE IS PROVIDED "AS IS", WITHOUT WARRANTY OF ANY KIND, EXPRESS OR
IMPLIED, INCLUDING BUT NOT LIMITED TO THE WARRANTIES OF MERCHANTABILITY,
FITNESS FOR A PARTICULAR PURPOSE AND NONINFRINGEMENT. IN NO EVENT SHALL THE
AUTHORS OR COPYRIGHT HOLDERS BE LIABLE FOR ANY CLAIM, DAMAGES OR OTHER
LIABILITY, WHETHER IN AN ACTION OF CONTRACT, TORT OR OTHERWISE, ARISING FROM,
OUT OF OR IN CONNECTION WITH THE SOFTWARE OR THE USE OR OTHER DEALINGS IN THE
SOFTWARE.
```

## Modular Wind Tunnel Design
- **Designer**: Jerrod Hofferth
- **License**: Creative Commons 4.0
- **Project**: Modular Wind Tunnel for STEM Education
- **Website**: https://www.printables.com/@JerrodH

---

For the full text of other licenses, please refer to the respective library repositories listed above.

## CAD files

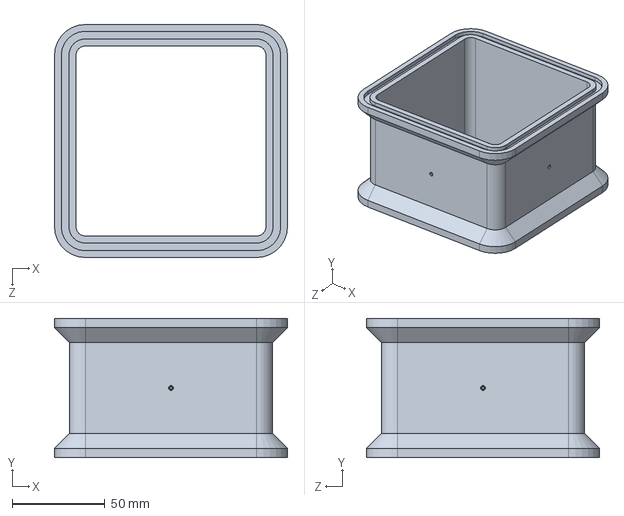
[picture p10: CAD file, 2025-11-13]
3D Print Files/5-6 - Small Duct Section with Static Pressure Taps.SLDPRT
125.6 x 75.0 x 125.6 mm

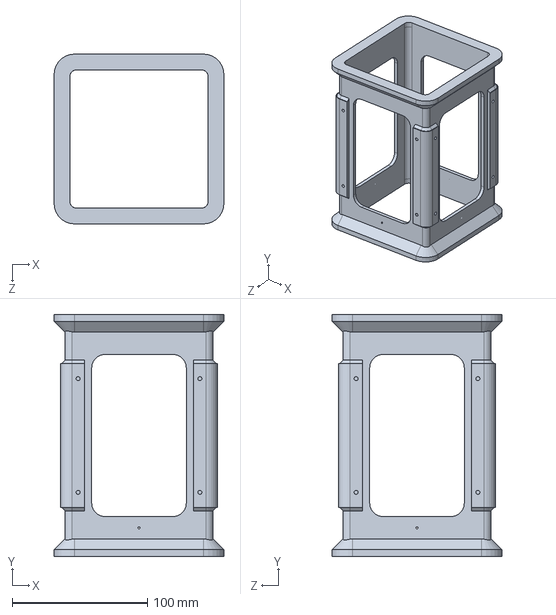
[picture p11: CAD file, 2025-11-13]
3D Print Files/Test Section with Static Pressure Ring and Fillet Windows.SLDPRT
125.6 x 179.0 x 125.6 mm

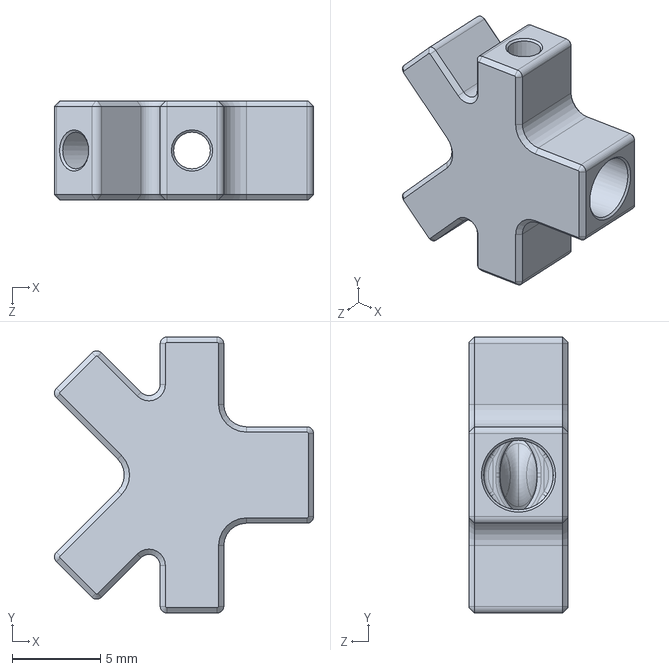
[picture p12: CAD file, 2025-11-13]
3D Print Files/Static Pressure Ring Manifold.SLDPRT
14.7 x 15.6 x 5.59 mm

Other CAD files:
3D Print Files/5-6 - Small Duct Section with Static Pressure Taps.3MF
3D Print Files/Static Pressure Ring Manifold.3MF
3D Print Files/Test Section with Static Pressure Ring and Fillet Windows.3MF

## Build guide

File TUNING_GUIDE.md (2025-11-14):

# Advanced PID Tuning Guide

**Recommendations from Claude Sonnet 4.5 on PID tuning for this repository. The content is determined to be suitably accurate by the author, but take all AI generated content with skepticism and critical thinking.**
**Repository:** [EDU-wind-tunnel](https://github.com/Low-Boom/EDU-wind-tunnel)

---

## Table of Contents
- [PID Basics](#pid-basics)
- [Understanding Each Term](#understanding-each-term)
- [Tuning Strategies](#tuning-strategies)
- [Auto-Tune Deep Dive](#auto-tune-deep-dive)
- [Manual Tuning Process](#manual-tuning-process)
- [Performance Optimization](#performance-optimization)
- [Troubleshooting Performance](#troubleshooting-performance)
- [Reference Tables](#reference-tables)

---

(Previous content from earlier in the message...)

### Problem: Oscillation

**Symptoms:**
- Bounces around setpoint
- Never settles
- ±0.5-2 m/s variation

**Diagnosis:**
```
Sustained oscillation = Too much gain

Check:
1. Kp too high (most common)
2. Ki too high
3. Mechanical resonance
4. Sensor noise
```

**Solutions:**
```
Immediate:
tune 12 4 15  # Low Kp, low Ki, high Kd

Then test incrementally:
tune 15 4 15
tune 18 4 15
tune 20 5 15  # Find stability threshold
```

### Problem: Integral Windup

**Symptoms:**
- Large overshoot after long error
- Slow to recover from disturbances
- PWM saturates at 255

**Diagnosis:**
```
Integral term accumulates when PWM saturated
System can't respond, but integral keeps growing
When error reduces, huge overshoot results
```

**Solutions:**
1. **Code already has anti-windup** (conditional integration)
2. Reduce Ki if still happening
3. Reduce setpoint if consistently hitting PWM limits

```
Before: tune 20 15 12  (high Ki)
After:  tune 20 8 12   (moderate Ki)
```

### Problem: Noise Amplification

**Symptoms:**
- PWM output jumpy
- Motor "buzzes"
- Output changes rapidly even when stable

**Diagnosis:**
```
Kd amplifies measurement noise
Check derivative term contribution
```

**Solutions:**
```
1. Reduce Kd:
   tune 20 8 8   # Was Kd=12

2. Increase averaging:
   avg 25        # More smoothing

3. Check sensor mounting:
   Vibration → noise → derivative action
```

---

## Reference Tables

### Quick Reference: Gain Effects

| Gain | ↑ Increase Effect | ↓ Decrease Effect |
|---|---|---|
| **Kp** | Faster response | Slower response |
|  | More overshoot | Less overshoot |
|  | May oscillate | More stable |
|  | Smaller steady error | Larger steady error |
| **Ki** | Eliminates SS error | May have SS error |
|  | More overshoot | Less overshoot |
|  | Windup risk | Stable |
|  | Slower disturbance recovery | Faster recovery |
| **Kd** | Less overshoot | More overshoot |
|  | Dampens oscillation | May oscillate |
|  | Sensitive to noise | Less noise sensitive |
|  | Faster settling | Slower settling |

### Typical Gain Ranges by Application

| Application | Kp | Ki | Kd | Avg | Notes |
|---|----|----|----|----|---|
| **Fast Response** | 30-40 | 10-15 | 15-20 | 3-5 | Competition/demo |
| **Balanced** | 20-25 | 6-10 | 10-15 | 15-20 | General use |
| **Stable** | 15-20 | 4-6 | 10-12 | 25-30 | Educational |
| **Precision** | 20-25 | 12-18 | 12-15 | 15-20 | Research/testing |

### Tuning Decision Tree

```
START
  ↓
Response too slow? ──YES──> Increase Kp by 30%
  ↓ NO
  ↓
Overshoots? ──YES──> Reduce Kp by 20%, Increase Kd by 30%
  ↓ NO
  ↓
Oscillates? ──YES──> Reduce Kp by 40%, Reduce Ki by 50%
  ↓ NO
  ↓
Steady-state error? ──YES──> Increase Ki by 30%
  ↓ NO
  ↓
✅ OPTIMAL TUNING
```

### Auto-Tune Success Checklist

Before auto-tuning:
- [ ] Sensor calibrated (`recal`)
- [ ] Target speed set (>2 m/s)
- [ ] Motor responds to PWM commands
- [ ] System can reach target speed
- [ ] No obstructions in tunnel

During auto-tune:
- [ ] Motor oscillating between HIGH and LOW
- [ ] Airspeed oscillating around target
- [ ] State changes visible in serial output
- [ ] 3 complete cycles detected

After auto-tune:
- [ ] Gains calculated successfully
- [ ] Gains within expected ranges
- [ ] Test with small setpoint change
- [ ] Fine-tune if needed

### Common Gain Combinations

| Scenario | Kp | Ki | Kd | Expected Behavior |
|---|----|----|----|---|
| **Default** | 31 | 12 | 10 | Moderate response, some overshoot |
| **Conservative** | 15 | 5 | 8 | Slow, stable, no overshoot |
| **Aggressive** | 35 | 15 | 18 | Fast, 10-20% overshoot |
| **Precision** | 22 | 15 | 13 | Slow approach, exact setpoint |
| **Noisy System** | 18 | 6 | 6 | Low derivative, more averaging |

---

## Advanced Topics

### Gain Scheduling

For systems needing different gains at different speeds:

```cpp
// Add to code after line with myPID.SetTunings()
void updateGainSchedule() {
    float speed = desiredAirSpeed;
    
    if (speed < 8.0) {
        // Low speed: gentle, precise
        Kp = 18.0;
        Ki = 6.0;
        Kd = 10.0;
    } else if (speed < 15.0) {
        // Medium speed: balanced
        Kp = 22.0;
        Ki = 8.0;
        Kd = 12.0;
    } else {
        // High speed: aggressive
        Kp = 28.0;
        Ki = 10.0;
        Kd = 15.0;
    }
    
    myPID.SetTunings(Kp, Ki, Kd);
}
```

Call in `loop()` when setpoint changes.

### Feed-Forward Control

For predictable disturbances:

```cpp
// Add feed-forward term based on target
float feedForward = desiredAirSpeed * 10.0;  // ~10 PWM per m/s
currPWM += feedForward;
```

Reduces reliance on feedback, faster response.

### Adaptive Tuning

Auto-adjust gains based on performance:

```cpp
// Pseudo-code concept
if (overshoot > 20%) {
    Kp *= 0.9;  // Reduce by 10%
}
if (settlingTime > 10.0) {
    Kp *= 1.1;  // Increase by 10%
}
```

Requires performance metrics tracking.

---

## Conclusion

**Remember:**
1. Start conservative, increase gradually
2. Auto-tune first, manual fine-tune second
3. Test thoroughly at different setpoints
4. Document your final gains
5. Safety first - start slow!

**Tuning is iterative:**
```
Tune → Test → Observe → Adjust → Repeat
```

**When in doubt:**
```
tune 20 8 12    # Good starting point for most systems
```

---

## sTune Advanced Autotuning (Optional)

### What is sTune?

sTune is an advanced open-loop PID autotuner that uses a novel inflection point test method. It's an alternative to the relay tuning method and offers several advantages:

**Benefits:**
- **Faster tuning**: Typically completes in ½τ (half the system time constant)
- **More stable**: Uses conservative tuning rules for minimal overshoot
- **Automatic step sizing**: Determines optimal test parameters automatically
- **Better process characterization**: Provides dead time, time constant, and process gain

**How it works:**
1. Applies a step change to the output (PWM)
2. Monitors the system response curve
3. Detects the inflection point using a moving tangent method
4. Calculates process characteristics (gain, dead time, tau)
5. Applies tuning rules to determine optimal PID gains

### Using sTune

**Prerequisites:**
- Install sTune library via Arduino Library Manager
- System must have S-shaped step response (first-order with delay)

**Basic usage:**
```
1. Set target airspeed: 10
2. Type: stune
3. Wait for tuning to complete (~30-60 seconds)
4. Gains automatically applied
```

**sTune vs Relay Tuning:**

| Feature | Relay Tuning | sTune |
|---|---|---|
| Method | Oscillation-based | Step response |
| Duration | ~30-60 seconds | ~30-60 seconds |
| Tuning style | Aggressive | Conservative |
| Overshoot | Some overshoot | Minimal/none |
| Process info | Limited | Detailed |
| Best for | Fast response | Stable operation |

**When to use sTune:**
- Educational environments where stability is critical
- Research applications requiring precise control
- Systems where overshoot must be minimized
- When you want detailed process characterization

**When to use relay tuning:**
- Fast, responsive control needed
- Competition or demonstration scenarios
- Quick tuning iterations desired
- Some overshoot is acceptable

### sTune Tuning Methods

sTune provides multiple tuning methods (configured in code):

1. **NoOvershoot_PID** (default): Conservative, stable response
2. **ZN_PID**: Ziegler-Nichols, moderate aggressiveness
3. **DampedOsc_PID**: Balanced response
4. **CohenCoon_PID**: Good for systems with delay
5. **Mixed_PID**: Average of all methods

The default configuration uses **NoOvershoot_PID** for maximum stability.

### Example sTune Output

```
[sTune] AUTOTUNING COMPLETE!
[sTune] Duration: 45 seconds
[sTune] Tuned PID Gains:
        Kp = 18.2456
        Ki = 7.8234
        Kd = 11.3421
[sTune] Process Characteristics:
        Process Gain: 0.8234
        Dead Time: 2.34 s
        Time Constant (Tau): 8.67 s
```

### Troubleshooting sTune

**Problem: Tuning times out**
- Increase test time estimate in code
- Check motor/fan responds to PWM
- Verify sensors are working
- Ensure target is achievable

**Problem: Poor gains**
- System may not have S-curve response
- Try increasing output step size
- Use relay tuning instead
- Check for mechanical issues

**Problem: Error during tuning**
- Target too low (must be ≥2 m/s)
- Emergency stop triggered
- Sensor malfunction
- Review serial output for details

### Customizing sTune Parameters

Advanced users can modify parameters in `STunePIDTuner.cpp`:

```cpp
// Change tuning method (in constructor)
_tuner = new sTune(input, output, 
                   sTune::ZN_PID,        // Try different method
                   sTune::directIP,      // Or direct5T for full test
                   sTune::printSUMMARY);

// Adjust in startTuning() call
tuner->startTuning(
    setpoint,     // Target speed
    30.0,         // Input span (max airspeed)
    255.0,        // Output span (PWM range)
    0.0,          // Output start
    100.0,        // Output step (adjust for system)
    60,           // Test time estimate (seconds)
    5,            // Settle time (seconds)
    300           // Number of samples
);
```

### References

- [sTune GitHub Repository](https://github.com/Dlloydev/sTune)
- [sTune Wiki](https://github.com/Dlloydev/sTune/wiki)
- [Inflection Point Method](https://en.wikipedia.org/wiki/Inflection_point)

---

## Conclusion

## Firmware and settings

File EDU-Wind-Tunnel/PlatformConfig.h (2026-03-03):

/*
 * PlatformConfig.h
 *
 * Platform-specific hardware configuration for the EDU Wind Tunnel Controller.
 * Provides sensible pin defaults and hardware settings for all supported boards.
 *
 * Edit DEFAULT_PWM_PIN / DEFAULT_TACH_PIN here if your wiring differs from the
 * defaults listed below.  All other sketch code stays unchanged.
 *
 * Supported platforms
 * -------------------
 *   Classic Arduino (AVR)    : Uno, Nano, Mega 2560
 *   Arduino MBED             : Uno R4, Giga R1
 *   ESP32-PICO (M5 Atom Stack) : M5 Atom Lite / M5 Atom Matrix
 *   ESP32-S3                 : Generic dev-boards
 *   ESP32-P4                 : Waveshare ESP32-P4 and other P4 dev-boards
 *   Generic ESP32            : Any other ESP32 board
 *
 * Copyright (c) 2025 Low-Boom
 * Licensed under MIT License
 */

#ifndef PLATFORM_CONFIG_H
#define PLATFORM_CONFIG_H

#include <Arduino.h>

// ============================================================
// ESP32 family  (ESP32-PICO, ESP32-S3, ESP32-P4, generic ESP32)
// Requires ESP32 Arduino core 2.0 or later (3.x for ESP32-P4).
// ============================================================
#if defined(ARDUINO_ARCH_ESP32)

  // ---- M5 Atom Stack / M5 Atom Lite (ESP32-PICO-D4) ----
  // Sensors connect to the Grove / HY2.0 bottom connector.
  // Grove pins: SDA = GPIO 26, SCL = GPIO 32
  #if defined(ARDUINO_M5Stack_ATOM_LITE) || defined(ARDUINO_M5Stack_ATOM) || \
      defined(ARDUINO_M5Atom)             || defined(ARDUINO_M5ATOM_LITE)
    #define I2C_SDA_PIN       26   // Grove SDA
    #define I2C_SCL_PIN       32   // Grove SCL
    #define DEFAULT_PWM_PIN   19   // Available GPIO (e.g. HAT header)
    #define DEFAULT_TACH_PIN  23   // Available GPIO (e.g. HAT header)

  // ---- Generic ESP32-S3 dev-board ----
  // Adjust I2C and PWM pins to match your wiring.
  #elif defined(CONFIG_IDF_TARGET_ESP32S3)
    #define I2C_SDA_PIN        8
    #define I2C_SCL_PIN        9
    #define DEFAULT_PWM_PIN   10
    #define DEFAULT_TACH_PIN  11

  // ---- ESP32-P4 (e.g. Waveshare ESP32-P4-WiFi6-Touch-LCD-7B) ----
  // Uses GPIO ≤ 36 to avoid LDO power issues on high-numbered pins.
  // WiFi is provided by an on-board ESP32-C6; GPIOs 14-19 are reserved for
  // the SDIO host interface to that companion chip — do NOT reassign them.
  #elif defined(CONFIG_IDF_TARGET_ESP32P4)
    #define I2C_SDA_PIN        7
    #define I2C_SCL_PIN        8
    #define DEFAULT_PWM_PIN    6
    #define DEFAULT_TACH_PIN   5

  // ---- Generic ESP32 (ESP32-WROOM, ESP32-WROVER, etc.) ----
  #else
    #define I2C_SDA_PIN       21
    #define I2C_SCL_PIN       22
    #define DEFAULT_PWM_PIN    9
    #define DEFAULT_TACH_PIN   2
  #endif

  // LED_BUILTIN fallback: many ESP32 boards don't define this in all BSPs.
  // Standard ESP32 DevKit uses GPIO 2; M5 Atom has an RGB LED on GPIO 27
  // (not a simple digital output, so we fall back to a safe GPIO here).
  #ifndef LED_BUILTIN
    #define LED_BUILTIN 2
  #endif

// ============================================================
// Classic Arduino / MBED (Uno, Mega, Giga R1, Uno R4, etc.)
// Wire.begin() with no arguments picks up the board-defined SDA/SCL.
// ============================================================
#else
  #define I2C_SDA_PIN       -1   // -1 = use board default (no args to Wire.begin)
  #define I2C_SCL_PIN       -1
  #define DEFAULT_PWM_PIN    9
  #define DEFAULT_TACH_PIN   2
#endif

#endif // PLATFORM_CONFIG_H

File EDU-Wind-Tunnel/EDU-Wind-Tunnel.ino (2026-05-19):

// Basic Arduino includes
#include <Arduino.h>
#include <Wire.h>

// Platform-specific pin and hardware configuration (ESP32, M5 Atom, classic Arduino)
#include "PlatformConfig.h"

// Sensor libraries
#include "DFRobot_BMP58X.h"
#include <DFRobot_LWLP.h>
#include <QuickPID.h>
#include "math.h"

// sTune library and wrapper (optional - for advanced autotuning)
#include <sTune.h>
#include "STunePIDTuner.h"

// I2C Scanner utility
#include "I2CScanner.h"

// sTune Configuration - User Selectable Tuning Method
// Available methods:
//   sTune::ZN_PID           - Ziegler-Nichols (moderate overshoot, fast response)
//   sTune::DampedOsc_PID    - Damped Oscillation (balanced)
//   sTune::NoOvershoot_PID  - No Overshoot (conservative, stable) [DEFAULT]
//   sTune::CohenCoon_PID    - Cohen-Coon (good for systems with delay)
//   sTune::Mixed_PID        - Mixed (average of all methods)
// For PI control, use: ZN_PI, DampedOsc_PI, NoOvershoot_PI, CohenCoon_PI, Mixed_PI
const sTune::TuningMethod STUNE_METHOD = sTune::Mixed_PID;

// MBED support
// #include "mbed.h"

#define SEALEVELPRESSURE_HPA (1013.25)
#define DPS_ADDRESS 0x00   // DFRobot LWLP5000 (SEN0343) — fixed I2C address
#define BMP_I2C_ADDRESS 0x47  // DFRobot BMP585 (SEN0665) — default I2C address (alt: 0x46)

// PID gains - Full PID control
float Kp = 25.0, Ki = 10.0, Kd = 15.0;

// Pin assignments (platform defaults set in PlatformConfig.h – edit there to change)
const int PWM_pin  = DEFAULT_PWM_PIN;    // Motor PWM control output
const int TACH_pin = DEFAULT_TACH_PIN;   // Tachometer pulse input
const int ENC_PPR = 2;
const float kI = 1;

const int MAX_PRESSURE = 14745.0;
const float MIN_PRESSURE = 1638.0;

const float MAX_AIRSPEED = 30.0;
const float MIN_AIRSPEED = 0.0;
const float Specific_gas_constant = 287.058;

// Pressure sensor calibration
float pressureOffset = 0.0;
bool calibrated = false;
int calibrationSamples = 50;  // Default calibration samples (adjustable)
const int MIN_CALIB_SAMPLES = 5;
const int MAX_CALIB_SAMPLES = 100;

// Sensor oversampling configuration
const int PRESSURE_OVERSAMPLES = 5;  // Read sensor 5 times per measurement

// Pressure sensor averaging configuration
int pressureAverageSamples = 20;  // Default: 20 samples
int savedAverageSamples = 20;     // Saved value during auto-tune
const int MAX_AVG_SAMPLES = 50;   // Maximum: 50 samples
const int MIN_AVG_SAMPLES = 1;
float pressureBuffer[MAX_AVG_SAMPLES];
int pressureBufferIndex = 0;
bool pressureBufferFilled = false;

// Temperature correction
float lastAirDensity = 1.225;  // Cache for display
float lastTemperature = 15.0;  // Cache for display

// Timing
const unsigned long updateInterval = 200;  // 200ms update interval
unsigned long lastUpdate = 0;
unsigned long startTime = 0;

unsigned int LastValidRPM = 0;
unsigned long LastRPMUpdateTime = 0;
const unsigned long RPM_TIMEOUT_MS = 1000;

// PWM Rate Limiting (disabled during tuning)
float lastPWMOutput = 0;
const float MAX_PWM_CHANGE_PER_CYCLE = 25.0;

// PID and control variables
float currPWM = 0;
float desiredAirSpeed = 0;
float currentAirSpeed = 0;

// Relay Auto-tuning configuration
const float MIN_TUNE_SETPOINT = 2.0;
bool autoTuning = false;
float tuneSetpoint = 0.0;
uint32_t tuneStartTime = 0;

// Relay tuning state
enum RelayState { RELAY_HIGH, RELAY_LOW };
RelayState relayState = RELAY_HIGH;
float relayOutputHigh = 0;
float relayOutputLow = 0;
float relayHysteresis = 0.5;  // m/s hysteresis band

// Oscillation detection
float peakHigh = -999;
float peakLow = 999;
unsigned long lastCrossingTime = 0;
unsigned long oscillationPeriod = 0;
int cycleCount = 0;
const int REQUIRED_CYCLES = 3;  // Need 3 complete cycles
bool firstCrossing = true;

// Accumulated measurements
float sumPeriods = 0;
float sumAmplitudes = 0;
int validCycles = 0;

// Debug
unsigned long debugCounter = 0;

// sTune autotuning (optional alternative to relay tuning)
STunePIDTuner *sTuner = nullptr;
bool sTuneActive = false;

// Forward declarations
void OnTachPulse();
void initializeBarometer();
void checkForUserAirspeedUpdate();
void calibratePressureSensor(bool skipWait = false, int numSamples = -1);
float readPressureSensorRawUncalibrated();
float readPressureSensorRaw();
float readPressureSensorOversampled();
float readPressureSensorAveraged();
float readBarometerSensor();
float calcCurrentAirSpeed(float pressure, float AirDensity);
unsigned int RPMcalc();
void startRelayTune(int pwmLow = -1, int pwmHigh = -1);
void runRelayTune();
void setPressureAverageSamples(int samples);
void startSTune();
void runSTune();

QuickPID myPID(&currentAirSpeed, &currPWM, &desiredAirSpeed);

DFRobot_LWLP lwlp;
DFRobot_BMP58X_I2C *bmp58x = nullptr;

volatile unsigned long LastPulseTime = 0;
volatile unsigned long PulseInterval = 0;
unsigned long PrevPulseInterval = 0;
bool changed = false;

void setup() {
    Serial.begin(115200);
    delay(2000);
    
    while(Serial.available()) Serial.read();
    
    Serial.println("\n\n");
    Serial.println("=====================================");
    Serial.println("   EDU Wind Tunnel PID Controller v1.1");
    Serial.println("   Sensors: DFRobot SEN0665 (BMP585) + SEN0343 (LWLP5000)");
    Serial.println("   Build: 2025-11-09 00:08:20 UTC");
    Serial.println("   User: Low-Boom");
    Serial.println("=====================================");
    Serial.flush();
    delay(100);

    // Initialize pressure buffer
    for (int i = 0; i < MAX_AVG_SAMPLES; i++) {
        pressureBuffer[i] = 0.0;
    }

    // Initialize I2C
    Serial.print("[INIT] I2C bus...");
    #if I2C_SDA_PIN >= 0
        Wire.begin(I2C_SDA_PIN, I2C_SCL_PIN);  // ESP32: explicit SDA/SCL
    #else
        Wire.begin();                            // Classic Arduino: use board defaults
    #endif
    Wire.setClock(400000);
    Serial.println(" OK (400kHz)");
    delay(100);

    // Scan all I2C buses for connected devices
    scanAllI2CBuses(Serial);
    
    // Configure differential pressure sensor (DFRobot SEN0343 / LWLP5000)
    // The LWLP5000 uses I2C address 0x00 (fixed), which is not scanned by the
    // standard I2C bus scanner.  Initialize it directly on Wire.
    Serial.print("[INIT] LWLP5000 differential pressure sensor (DFRobot SEN0343)...");
    if (lwlp.begin() != 0) {
        Serial.println(" FAILED!");
        Serial.println("[ERROR] Cannot communicate with differential pressure sensor");
        Serial.println("[ERROR] Check SEN0343 connections to Wire (SDA/SCL)");
        while (1) {
            digitalWrite(LED_BUILTIN, !digitalRead(LED_BUILTIN));
            delay(200);
        }
    }
    Serial.println(" OK");
    Serial.print("        Oversampling: "); Serial.print(PRESSURE_OVERSAMPLES); 
    Serial.println("x per reading");
    Serial.print("        Averaging: "); Serial.print(pressureAverageSamples); 
    Serial.println(" samples");
    delay(100);

    // Initialize barometer
    initializeBarometer();

    // Initialize hardware
    Serial.println("[INIT] Motor & Tachometer...");
    Serial.print("        PWM Pin: "); Serial.println(PWM_pin);
    Serial.print("        TACH Pin: "); Serial.println(TACH_pin);
    
    pinMode(PWM_pin, OUTPUT);
    analogWrite(PWM_pin, 0);  // Start at 0
    
    pinMode(TACH_pin, INPUT_PULLUP);
    pinMode(LED_BUILTIN, OUTPUT);
    attachInterrupt(digitalPinToInterrupt(TACH_pin), OnTachPulse, FALLING);
    
    Serial.println("        OK");
    delay(100);

    // Calibrate pressure sensor with 30 second wait (startup only)
    calibratePressureSensor(false);

    // Configure QuickPID for full PID control
    Serial.print("[INIT] QuickPID Controller (Full PID)...");
    myPID.SetTunings(Kp, Ki, Kd);
    myPID.SetOutputLimits(0, 255);
    myPID.SetSampleTimeUs(updateInterval * 1000);
    myPID.SetMode(QuickPID::Control::automatic);
    
    // OPTIMIZED SETTINGS FOR LAGGY SYSTEMS - Full PID
    myPID.SetProportionalMode(QuickPID::pMode::pOnMeas);      // P on Measurement
    myPID.SetDerivativeMode(QuickPID::dMode::dOnMeas);        // D on Measurement
    myPID.SetAntiWindupMode(QuickPID::iAwMode::iAwCondition); // Conditional integration
    
    Serial.println(" OK");
    Serial.print("        Update Rate: "); Serial.print(updateInterval); Serial.println(" ms");
    Serial.print("        Kp="); Serial.print(Kp, 1);
    Serial.print(", Ki="); Serial.print(Ki, 1);
    Serial.print(", Kd="); Serial.println(Kd, 1);
    Serial.println("        P-on-Measurement: ENABLED");
    Serial.println("        D-on-Measurement: ENABLED");
    Serial.println("        Conditional Anti-Windup: ENABLED");
    Serial.print("        PWM Rate Limit: ±"); 
    Serial.print(MAX_PWM_CHANGE_PER_CYCLE); 
    Serial.println(" per cycle");
    delay(100);

    // Initialize sTune wrapper (optional advanced autotuning)
    Serial.print("[INIT] sTune wrapper...");
    sTuner = new STunePIDTuner(&currentAirSpeed, &currPWM, STUNE_METHOD);
    sTuner->setEmergencyStop(MAX_AIRSPEED);
    Serial.println(" OK");
    Serial.print("        Tuning Method: ");
    Serial.println(sTuner->getTuningMethodName());
    Serial.println("        Advanced autotuning available via 'stune' command");
    delay(100);

    startTime = millis();
    
    Serial.println("=====================================");
    Serial.println("[READY] System initialized!");
    Serial.println("");
    Serial.println("HARDWARE:");
    Serial.print("  PWM Output: Pin "); Serial.println(PWM_pin);
    Serial.print("  Tachometer: Pin "); Serial.println(TACH_pin);
    Serial.println("");
    Serial.println("CONTROL:");
    Serial.println("  Type airspeed value (m/s) to set target");
    Serial.println("  Example: '10' sets target to 10 m/s");
    Serial.println("");
    Serial.println("COMMANDS:");
    Serial.println("  tune                    - Auto PWM range");
    Serial.println("  tune <low> <high>       - Manual PWM range");
    Serial.println("    Example: 'tune 40 100'");
    Serial.println("  tune <Kp> <Ki> <Kd>     - Manual PID gains");
    Serial.println("    Example: 'tune 20 8 12'");
    Serial.println("  recal [N]               - Recalibrate sensor");
    Serial.println("  avg N                   - Set averaging samples");
    Serial.println("  stune                   - sTune autotuning (advanced)");
    Serial.println("");
    Serial.println("AUTO-TUNE:");
    Serial.println("  Method: Relay + Aggressive Tuning Rules");
    Serial.println("  Tuning: 'Some Overshoot' for fast response");
    Serial.println("  1. Set target airspeed (min 2 m/s)");
    Serial.println("  2. Type 'tune' or 'tune <low> <high>'");
    Serial.println("  3. System oscillates 3-4 cycles");
    Serial.println("  4. Aggressive PID gains calculated");
    Serial.println("  Duration: ~30-60 seconds");
    Serial.println("  Tip: Start conservative (e.g., tune 40 100)");
    Serial.println("");
    Serial.println("STUNE AUTO-TUNE (ADVANCED):");
    Serial.println("  Method: Inflection Point (Set Mode at Compile)");
    Serial.println("  Tuning: Stable response, minimal overshoot");
    Serial.println("  1. Set target airspeed (min 2 m/s)");
    Serial.println("  2. Type 'stune'");
    Serial.println("  3. System applies step and monitors response");
    Serial.println("  4. Conservative PID gains calculated");
    Serial.println("  Duration: ~30-60 seconds");
    Serial.println("  Benefits: More stable than relay tuning");
    Serial.println("");
    Serial.println("MANUAL TUNING:");
    Serial.println("  tune <Kp> <Ki> <Kd> - Directly set gains");
    Serial.println("  Example: tune 20 8 12");
    Serial.println("  Ranges: Kp(1-100), Ki(0.1-50), Kd(0.1-50)");
    Serial.println("");
    Serial.println("DATA FORMAT:");
    Serial.println("  T(s) | V | Target | PWM | P(Pa) | Temp(°C) | Err");
    Serial.println("=====================================\n");
    
    lastUpdate = millis();
}

void loop() {
    unsigned long now = millis();
    
    if (now - lastUpdate >= updateInterval) {
        lastUpdate = now;
        debugCounter++;
        
        // Read sensors with advanced processing
        float currPressure = readPressureSensorAveraged();   // Oversampled + Averaged
        float currAirDensity = readBarometerSensor();        // Temperature compensated
        currentAirSpeed = calcCurrentAirSpeed(currPressure, currAirDensity);

        if (sTuneActive) {
            // sTune autotuning mode
            runSTune();
        } else if (!autoTuning) {
            checkForUserAirspeedUpdate();
            
            // Normal PID control
            myPID.Compute();
            
            // Apply PWM with rate limiting
            int pwmOut = constrain((int)round(currPWM), 0, 255);
            float pwmChange = pwmOut - lastPWMOutput;
            if (abs(pwmChange) > MAX_PWM_CHANGE_PER_CYCLE) {
                pwmChange = (pwmChange > 0) ? MAX_PWM_CHANGE_PER_CYCLE : -MAX_PWM_CHANGE_PER_CYCLE;
                pwmOut = lastPWMOutput + pwmChange;
            }
            lastPWMOutput = pwmOut;
            analogWrite(PWM_pin, pwmOut);
            
        } else {
            // Relay auto-tuning mode - DIRECT CONTROL
            runRelayTune();
        }

        unsigned long elapsed = (now - startTime) / 1000;
        float error = desiredAirSpeed - currentAirSpeed;

        // Print data
        if (sTuneActive) {
            Serial.print("[sTune] ");
            Serial.print(sTuner->getStatusString()); Serial.print(" | ");
        } else if (autoTuning) {
            Serial.print("[TUNE] ");
            uint32_t tuneElapsed = (millis() - tuneStartTime) / 1000;
            Serial.print(tuneElapsed); Serial.print("s | ");
            Serial.print("Cycle:"); Serial.print(cycleCount); Serial.print(" | ");
        } else {
            Serial.print(elapsed); Serial.print("s | ");
        }
        Serial.print("V:"); Serial.print(currentAirSpeed, 2); Serial.print(" | ");
        Serial.print("T:"); Serial.print(desiredAirSpeed, 2); Serial.print(" | ");
        Serial.print("PWM:"); Serial.print((int)round(currPWM)); Serial.print(" | ");
        Serial.print("P:"); Serial.print(currPressure, 2); Serial.print(" | ");
        Serial.print("T:"); Serial.print(lastTemperature, 1); Serial.print("°C | ");
        Serial.print("Err:"); Serial.print(error, 2);
        
        // Show PID values and averaging every 20 readings
        if (debugCounter % 20 == 0 && !autoTuning && !sTuneActive) {
            Serial.print(" | Kp:"); Serial.print(Kp, 1);
            Serial.print(" Ki:"); Serial.print(Ki, 1);
            Serial.print(" Kd:"); Serial.print(Kd, 1);
            Serial.print(" Avg:"); Serial.print(pressureAverageSamples);
        }
        
        Serial.println();
    }
}

void startRelayTune(int pwmLow, int pwmHigh) {
    if (desiredAirSpeed < MIN_TUNE_SETPOINT) {
        Serial.println("\n[TUNE] ERROR: Target too low for auto-tune");
        Serial.print("[TUNE] Minimum target: ");
        Serial.print(MIN_TUNE_SETPOINT, 2);
        Serial.println(" m/s");
        Serial.println("[TUNE] Set a higher target speed first (e.g., 10)");
        Serial.println("[TUNE] Then type 'tune' to start\n");
        return;
    }
    
    // SAVE CURRENT AVERAGING BEFORE CHANGING IT
    savedAverageSamples = pressureAverageSamples;
    
    // REDUCE AVERAGING FOR FASTER TUNING RESPONSE
    // setPressureAverageSamples(3);  // Keep some averaging for noise reduction
    
    Serial.println("\n=====================================");
    Serial.println("[RELAY TUNE] AUTO-TUNE STARTING");
    Serial.println("=====================================");
    Serial.print("[RELAY] Target airspeed: ");
    Serial.print(desiredAirSpeed, 2);
    Serial.println(" m/s");
    Serial.println("[RELAY] Method: Åström-Hägglund Relay");
    Serial.println("[RELAY] Tuning Rules: AGGRESSIVE (Some Overshoot)");
    // Serial.print("[RELAY] Averaging temporarily set to 3 (was ");
    // Serial.print(savedAverageSamples);
    Serial.println(")");
    
    // Calculate relay outputs
    if (pwmLow > 0 && pwmHigh > 0) {
        // Manual PWM range provided
        relayOutputLow = constrain(pwmLow, 0, 255);
        relayOutputHigh = constrain(pwmHigh, 0, 255);
        
        if (relayOutputLow >= relayOutputHigh) {
            Serial.println("[ERROR] PWM Low must be less than PWM High!");
            Serial.println("        Example: tune 40 100");
            setPressureAverageSamples(savedAverageSamples);
            return;
        }
        
        Serial.println("[RELAY] PWM Range: MANUAL");
    } else {
        float estimatedPWM = desiredAirSpeed * 8; // Ball park sensitivity
        relayOutputHigh = constrain(round(estimatedPWM) + 20, 40, 245);
        relayOutputLow = constrain(round(estimatedPWM) - 20, 20, 150);
        
        Serial.println("[RELAY] PWM Range: AUTO-ESTIMATED");
        Serial.println("        Tip: If tuning fails, try manual range");
        Serial.println("        Example: tune 40 100");
    }
    
    Serial.println("[RELAY] Configuration:");
    Serial.print("        PWM High: "); Serial.println((int)relayOutputHigh);
    Serial.print("        PWM Low: "); Serial.println((int)relayOutputLow);
    Serial.print("        PWM Delta: "); Serial.println((int)(relayOutputHigh - relayOutputLow));
    Serial.print("        Hysteresis: ±"); Serial.print(relayHysteresis); Serial.println(" m/s");
    Serial.print("        Required cycles: "); Serial.println(REQUIRED_CYCLES);
    Serial.println("[RELAY] Process:");
    Serial.println("        1. Oscillate PWM between high/low");
    Serial.println("        2. Measure oscillation period & amplitude");
    Serial.println("        3. Calculate AGGRESSIVE PID gains");
    Serial.println("        Expected: Faster response, some overshoot");
    Serial.println("        Duration: ~30-60 seconds");
    Serial.println("=====================================");
    
    // Initialize relay tuning state
    tuneSetpoint = desiredAirSpeed;
    tuneStartTime = millis();
    relayState = RELAY_HIGH;
    
    peakHigh = -999;
    peakLow = 999;
    cycleCount = 0;
    firstCrossing = true;
    sumPeriods = 0;
    sumAmplitudes = 0;
    validCycles = 0;
    
    // Set PWM to LOW and start
    relayState = RELAY_LOW;
    currPWM = relayOutputLow;
    analogWrite(PWM_pin, (int)relayOutputLow);
    delay(500);
    // Verify it was written
    Serial.print("[RELAY] currPWM variable = ");
    Serial.println(currPWM, 1);
    Serial.println("[RELAY] Tuning active");
    
    autoTuning = true;
}
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

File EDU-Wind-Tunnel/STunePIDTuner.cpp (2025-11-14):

/*
 * STunePIDTuner.cpp
 * 
 * Wrapper class implementation for sTune library integration
 * 
 * Copyright (c) 2025 Low-Boom
 * Licensed under MIT License
 */

#include "STunePIDTuner.h"

STunePIDTuner::STunePIDTuner(float *input, float *output, sTune::TuningMethod tuningMethod)
    : _input(input),
      _output(output),
      _setpoint(0.0),
      _status(IDLE),
      _startTime(0),
      _timeout(120000), // Default 120 second timeout
      _kp(0.0),
      _ki(0.0),
      _kd(0.0),
      _gainsValid(false),
      _tuningMethod(tuningMethod),
      _inputSpan(30.0),
      _outputSpan(255.0),
      _outputStart(0.0),
      _outputStep(100.0),
      _testTimeSec(60),
      _settleTimeSec(5),
      _samples(300) {
    
    // Create sTune instance with selected tuning method
    _tuner = new sTune(input, output, _tuningMethod, sTune::directIP, sTune::printSUMMARY);
}

STunePIDTuner::~STunePIDTuner() {
    if (_tuner != nullptr) {
        delete _tuner;
        _tuner = nullptr;
    }
}

bool STunePIDTuner::startTuning(float setpoint, float inputSpan, float outputSpan,
                                 float outputStart, float outputStep,
                                 uint32_t testTimeSec, uint32_t settleTimeSec,
                                 uint16_t samples) {
    
    if (setpoint <= 0.0) {
        Serial.println("[sTune] ERROR: Invalid setpoint (must be > 0)");
        _status = ERROR;
        return false;
    }

    // Store configuration
    _setpoint = setpoint;
    _inputSpan = inputSpan;
    _outputSpan = outputSpan;
    _outputStart = outputStart;
    _outputStep = outputStep;
    _testTimeSec = testTimeSec;
    _settleTimeSec = settleTimeSec;
    _samples = samples;
    
    // Reset state
    _gainsValid = false;
    _kp = 0.0;
    _ki = 0.0;
    _kd = 0.0;
    
    // Configure sTune
    _tuner->Configure(inputSpan, outputSpan, outputStart, outputStep, 
                      testTimeSec, settleTimeSec, samples);
    
    // Calculate timeout: settle time + test time + 50% margin
    _timeout = (settleTimeSec + testTimeSec) * 1500; // milliseconds
    _startTime = millis();
    _status = SETTLING;
    
    Serial.println("\n=====================================");
    Serial.println("[sTune] AUTOTUNING STARTED");
    Serial.println("=====================================");
    Serial.print("[sTune] Target setpoint: "); Serial.print(_setpoint, 2); Serial.println(" m/s");
    Serial.print("[sTune] Method: Inflection Point ("); Serial.print(getTuningMethodName()); Serial.println(")");
    Serial.println("\n[sTune] Configuration:");
    Serial.print("        Input span: "); Serial.print(inputSpan, 1); Serial.println(" m/s");
    Serial.print("        Output span: "); Serial.print(outputSpan, 0); Serial.println(" PWM");
    Serial.print("        Output start: "); Serial.print(outputStart, 0); Serial.println(" PWM");
    Serial.print("        Output step: "); Serial.print(outputStep, 0); Serial.println(" PWM");
    Serial.print("        Test time: "); Serial.print(testTimeSec); Serial.println(" sec");
    Serial.print("        Settle time: "); Serial.print(settleTimeSec); Serial.println(" sec");
    Serial.print("        Samples: "); Serial.println(samples);
    Serial.print("        Timeout: "); Serial.print(_timeout / 1000); Serial.println(" sec");
    Serial.println("=====================================");
    Serial.println("[sTune] Starting settling phase...");
    
    return true;
}

STunePIDTuner::TuningStatus STunePIDTuner::update() {
    // Check timeout
    if (_status != IDLE && _status != COMPLETED && _status != ERROR) {
        if (millis() - _startTime > _timeout) {
            Serial.println("\n[sTune] TIMEOUT!");
            Serial.println("[sTune] Tuning took too long - aborting");
            Serial.print("[sTune] Duration: "); Serial.print((millis() - _startTime) / 1000);
            Serial.println(" seconds");
            Serial.println("[sTune] Troubleshooting:");
            Serial.println("        - Check if system responds to output step");
            Serial.println("        - Verify sensors are working correctly");
            Serial.println("        - Try larger output step");
            Serial.println("        - Increase test time estimate");
            _status = TIMEOUT;
            return _status;
        }
    }

    // Run sTune state machine
    if (_status == SETTLING || _status == TESTING) {
        uint8_t tuneResult = _tuner->Run();
        
        switch (tuneResult) {
            case sTune::sample:
                // Active sampling during test
                if (_status == SETTLING) {
                    _status = TESTING;
                    Serial.println("[sTune] Settling complete - starting test");
                    Serial.println("[sTune] Monitoring inflection point...");
                }
                break;
                
            case sTune::tunings: {
                // Tuning completed successfully
                _tuner->GetAutoTunings(&_kp, &_ki, &_kd);
                _gainsValid = true;
                _status = COMPLETED;
                
                unsigned long duration = (millis() - _startTime) / 1000;
                
                Serial.println("\n=====================================");
                Serial.println("[sTune] AUTOTUNING COMPLETE!");
                Serial.println("=====================================");
                Serial.print("[sTune] Duration: "); Serial.print(duration); Serial.println(" seconds");
                Serial.println("[sTune] Tuned PID Gains:");
                Serial.print("        Kp = "); Serial.println(_kp, 4);
                Serial.print("        Ki = "); Serial.println(_ki, 4);
                Serial.print("        Kd = "); Serial.println(_kd, 4);
                Serial.println("[sTune] Process Characteristics:");
                Serial.print("        Process Gain: "); Serial.println(getProcessGain(), 4);
                Serial.print("        Dead Time: "); Serial.print(getDeadTime(), 2); Serial.println(" s");
                Serial.print("        Time Constant (Tau): "); Serial.print(getTau(), 2); Serial.println(" s");
                Serial.print("[sTune] Tuning method: "); Serial.println(getTuningMethodName());
                Serial.println("[sTune] Gains ready to apply");
                Serial.println("=====================================\n");
                break;
            }
                
            case sTune::runPid:
                // This shouldn't happen in our use case
                break;
        }
    }
    
    return _status;
}

bool STunePIDTuner::isFinished() {
    return (_status == COMPLETED || _status == TIMEOUT || _status == ERROR);
}

bool STunePIDTuner::getTunedGains(float &kp, float &ki, float &kd) {
    if (!_gainsValid || _status != COMPLETED) {
        return false;
    }
    
    kp = _kp;
    ki = _ki;
    kd = _kd;
    return true;
}
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

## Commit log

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2025-11-12 Update critical motor power supply and sensor info
    Clarified motor power supply requirements and added precision expectations for the MS4525DO sensor.
2025-11-12 Enhance README with hardware setup details
    Added hardware setup section with quick connections and power supply warnings.
2025-11-12 Revise hardware configuration guide for Wind Tunnel Controller
    Updated the hardware configuration guide with detailed wiring, component guidance, and safety notes for the Wind Tunnel Controller. Added required components, pin mapping, wiring summary, power recom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
2025-11-12 Revise hardware configuration and component details
    Updated the hardware configuration guide to reflect changes in component requirements and wiring instructions.
2025-11-12 Revise sensor processing descriptions in README
    Updated sensor processing section for clarity and consistency.
2025-11-12 Add note on Arduino Giga Display Shield drivers
    Added note about broken drivers for Arduino Giga Display Shield.
2025-11-12 Revise hardware components and recommendations
    Updated hardware requirements and recommendations for the educational wind tunnel project, including specific fan models and tubing options.
2025-11-12 Update hardware recommendations in HARDWARE.md
    Added additional options for stainless steel tubing and clarified specifications.
2025-11-12 Update hardware recommendations in HARDWARE.md
    Removed deprecated tubing options and clarified requirements.
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2025-11-13 Fix Arduino badge links and update section title
    Updated Arduino badge links and modified section titles.
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2025-11-13 Revise hardware documentation and add new components
    Updated hardware components list and added details for tubing and cabling.
2025-11-13 Update hardware requirements in README
    Added information about the Bi-Directional Logic Level Lifter requirement based on board and fan combination.
2025-11-13 Revise hardware requirements and wiring instructions
    Updated hardware requirements and wiring configurations for Arduino Mega 2560 and Giga R1 with various fan types. Added notes on PWM standards and logic level shifting for compatibility.
2025-11-13 CAD Files Added
    [5-6 - Small Duct Section with Static Pressure Taps.3MF, 5-6 - Small Duct Section with Static Pressure Taps.SLDPRT, Static Pressure Ring Manifold.3MF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]
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2025-11-14 Fix compilation errors: add braces to switch case and move example to separate directory
    [STunePIDTuner.cpp]
2025-11-14 Fix typo in coursework materials description
2025-11-14 Add Android USB control instructions to README
    Added instructions for controlling the Arduino via Android using a USB connection.
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2025-11-17 Fix I2C scanner hanging issue by adding proper STOP condition and delay
    [I2CScanner.cpp]
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2025-11-17 Fix Wire bus hanging by initializing Wire1 and Wire2 before scanning
    [I2CScanner.cpp]
2025-11-17 Add I2C timeout to prevent hanging when no devices connected
    [I2CScanner.cpp]
2025-11-17 Fix I2C scanner hanging on Uno Rev 4 with empty Wire bus
    [I2CScanner.cpp]
2025-11-17 Add Wire bus responsiveness test to prevent hangs on Uno Rev4
    [I2CScanner.cpp]
2025-11-17 Disable Wire scanning on multi-bus boards to prevent hangs
    [I2CScanner.cpp]
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2025-11-17 Add early abort logic to prevent long Wire scan delays
    [I2CScanner.cpp]
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2025-11-17 Enhance README with safety and I2C scanner info
    Added safety warnings and I2C device scanner section to README.
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2025-11-17 Revise hardware components and fan wiring instructions
    Updated hardware recommendations and clarified pin mapping details. Improved descriptions for using different types of fans with Arduino boards.
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2025-11-17 Update I2C wiring and power supply details
    Clarify power supply requirements for airspeed sensor and BMP390 barometer. Update I2C wiring configurations for Arduino Uno R4.
2026-01-05 Update wiring configuration details for Arduino and fan
    Clarified wiring configuration details for Arduino boards and AC Infinity fan. Added caution about power limits for third-party boards.
2026-01-05 Reorganize wiring configuration details in HARDWARE.md
    Rearranged the explanation of wiring configuration and third-party board limits for clarity.
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2026-03-03 Revise hardware requirements and ESP32 pin mapping
    Updated the required components section with additional details on Arduino and ESP32 microcontrollers. Improved formatting and clarified notes regarding compatibility and wiring.
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2026-05-19 feat: replace MS4525DO+BMP3XX with DFRobot SEN0343+SEN0665
    - Replace Adafruit_BMP3XX / ms4525do libraries with DFRobot_BMP58X
    (SEN0665 / BMP585) and DFRobot_LWLP (SEN0343 / LWLP5000)
    - Update I2C addresses: DPS 0x28→0x00 (LWLP fixed addr), BMP 0x77→0x47
    - Swap sensor objects: DFRobot_LWLP lwlp and DFRobot_BMP58X_I2C *bmp58x
    - Skip bus-scanner step for LWLP (addr 0x00 not detectable by scanner);
    initialize directly on Wire
    - Use pointer + new for BMP58X to support multi-bus detection
    - Update readPressureSensorRaw*, readBarometerSensor, initializeBarometer
    - Add sanity-check guard in readBarometerSensor for implausible readings
    - Update startup banner, HARDWARE.md, and README.md libra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
    [EDU-Wind-Tunnel.ino]
2026-05-19 docs: replace all remaining old-sensor references with DFRobot part numbers + chip IDs
    README.md:
    - I2C scanner Expected Output: update addresses (0x28/0x77 → 0x47), explain
    that LWLP5000 at 0x00 is expected to be absent from scan
    - License section: replace Adafruit BMP3XX / Bolder Flight MS4525DO entries
    with DFRobot_BMP58X (SEN0665 / BMP585) and DFRobot_LWLP (SEN0343 / LWLP5000)
    - Acknowledgments: replace Adafruit/Bolder Flight credits with DFRobot
    HARDWARE.md:
    - M5 Atom Stack note: remove MS4525DO 5 V requirement; both new sensors are 3.3 V
    - I2C Wiring section: rewrite to reflect both sensors being 3.3 V / Qwiic
    compatible; clarify LWLP5000 address 0x00 scanner behaviour
    - Airsp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
2026-05-19 Modify prerequisites in README
    Updated prerequisites to include ESP32 and Arduino microcontroller boards.
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2026-10-20 Fix C1: use ESP32 Wire timeout API in I2C scanner
    The ESP32 TwoWire class has no setWireTimeout()/clearWireTimeoutFlag(),
    so the scanner did not compile for ESP32. Use setTimeOut() (ms) there,
    setWireTimeout() (us) on Renesas and WIRE_HAS_TIMEOUT cores, and clear
    the timeout flag only where it exists. Move the WIRE_INTERFACES_COUNT
    fallback to file scope.
    Claude-Session: https://claude.ai/code/session_0155oUTZE4dKjYF19pevaZwD
2026-10-20 Fix H1: drive fan PWM low at boot and halt safely on errors
    The fan pin floated during the 2 s serial wait, sensor init and I2C scan.
    Make it an output driven LOW as the very first statements of setup(),
    set up the status LED only when the board has one, and route every
    fatal sensor error through haltWithError(), which keeps the fan off and
    blinks the LED forever.
    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
2026-10-20 Fix H4/H5a: read serial commands in every mode with a strict parser
    Serial input was only read in normal PID mode, so a running tune could
    not be stopped, and readStringUntil() blocked loop() for up to 1 s.
    - loop() now runs: read sensors -> handle commands -> control dispatch.
    A command that starts or ends a tune skips the control step of that
    pass, so no PID Compute()/PWM write follows a tune start.
    - Non-blocking line reader (64-byte buffer, LF/CR/CRLF, overflow and
    blank lines handled), case-insensitive keywords, strict decimal
    parsing (no trailing junk, nan or inf), unknown input -> hint to help.
    - `0`/`stop` stop the fan at once (PWM 0, target 0, PID re-initialised)
    and abor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
2026-10-20 Fix H2/H3: keep pressure signed and unify sensor calibration
    Raw readings were clamped to >= 0 before the offset and the moving
    average, which biased the average (and the airspeed) upward near zero
    and made the "valid read" checks and the calibration-failure branch
    dead code.
    - Pipeline: raw read -> minus offset -> moving average of signed
    values; clamp to >= 0 only inside the airspeed formula.
    - One calibratePressureSensor(N) for startup and `recal`: always stops
    the fan first, waits CALIBRATION_SETTLE_S = 15 s with a countdown,
    takes N raw samples, offset = mean, reports min/max and the true
    standard deviation.
    - Remove the dead validity checks, the failure branch and the
    `calib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
2026-10-20 Fix H6: never Reset() the PID, hand over bumplessly
    QuickPID::Reset() zeroes the integral and lastInput, so every setpoint
    change or gain change dropped the output to about 0 and then kicked the
    derivative term.
    - Setpoint change: only set the setpoint.
    - Manual gains: SetTunings() only.
    - Every hand-over to the PID (after a tune, after stop or abort, after
    calibration) uses pidBumplessStart(): QuickPID manual -> active mode,
    which runs Initialize() with the present output and input.
    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
2026-10-20 Fix M1/M2: fit sensor reads and sTune into the 200 ms loop
    - PRESSURE_OVERSAMPLES = 1: each LWLP read blocks about 60 ms, so five
    reads (300 ms) overran the 200 ms update interval.
    - QuickPID runs in timer mode: loop() already paces Compute() once per
    updateInterval, and QuickPID's own micros() check could skip passes.
    - Print a rate-limited warning when one update pass takes longer than
    updateInterval (blocking commands such as recal are excluded).
    - sTune: service the wrapper on every loop() pass (Run() needs two calls
    per processed sample) and write PWM only when it changes.
    - STunePIDTuner: re-apply the stored emergency stop after Configure(),
    report TESTING only once the settl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
2026-10-20 Fix H5: correct relay auto-tune math and tune hand-over
    - Ku = 4d/(pi*a) with d = (high-low)/2, in PWM per m/s (the /255 made
    the gains 255 times too small before clamping).
    - Pessen integral rule: Kp = 0.7 Ku, Ki = 1.75 Ku/Tu, Kd = 0.105 Ku Tu
    (Kd was 0.15 Ku Tu); labelled as such in the output.
    - One set of gain limits (Kp 1-100, Ki 0.1-50, Kd 0.1-50) shared by the
    manual command, the relay tune and sTune; clamped gains are reported.
    - Reset peak tracking at every HIGH->LOW switch, including the first.
    - Return after completion, so the timeout check cannot fire in the same
    pass. Timeout, sTune errors and user abort share abortTuning().
    - On success both tuners apply the gains, keep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
2026-10-20 Fix M3/M4/C2: limit PlatformConfig to ESP32-P4 and Uno R4
    Support exactly the boards the project targets and fail the build with
    a clear #error on any other ESP32 chip or board, instead of silently
    compiling with guessed pins (the generic ESP32 branch, for example,
    put the fan on GPIO 9, a flash pin on most ESP32 modules).
    - Two branches: ESP32-P4 and Uno R4 Minima/WiFi. Defines BOARD_NAME,
    I2C_SDA_PIN/I2C_SCL_PIN, FAN_PWM_PIN (P4: 6, R4: 9),
    FAN_PWM_FREQUENCY_HZ (P4: 25 kHz, R4: core default) and
    STATUS_LED_PIN (LED_BUILTIN or -1).
    - Remove the unused tachometer pin and the LED_BUILTIN fallback.
    - Drop Giga/Mbed/AVR/M5/S3 code paths and comments, including the
    Wire2 scan and the WI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
2026-10-20 Fix M5/M6/M7: airspeed limit, in-PID rate limit, one PWM writer
    - M5: MAX_AIRSPEED = 28 m/s; the LWLP5000 is rated to 500 Pa, which is
    28.6 m/s at 1.225 kg/m3, so 30 m/s targets were beyond the sensor.
    - M6: the PWM rate limit now lives inside the PID. Before each Compute()
    the output limits are set to +/-25 around the applied PWM, so the
    integral is clamped with it instead of winding up behind an external
    limiter. pidBumplessStart() restores 0..255.
    - One setFanPwm() is the only analogWrite() caller. It stores the
    applied PWM, skips unchanged writes and, on ESP32, sets
    FAN_PWM_FREQUENCY_HZ before the first write.
    - M7: keep the cores' default 100 kHz I2C clock instead of forcing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
2026-10-20 Clean up low-severity items: dead code, names, banner, data line
    - Remove dead code: tachometer ISR/RPMcalc and their volatiles, ENC_PPR,
    kI, MAX/MIN_PRESSURE, MIN_AIRSPEED, SEALEVELPRESSURE_HPA, DPS_ADDRESS,
    `changed`, PrevPulseInterval and leftover delays.
    - Barometer: look up 0x47, then 0x46, in the scan registry and create
    the driver once with the found address (no new/delete retry, fixes
    -Wdelete-non-virtual-dtor).
    - Data line: `SP:` for the setpoint, `Temp:` without unit suffix, and
    `PWM:` shows the PWM actually applied to the fan.
    - Banner: FIRMWARE_VERSION "1.3", build date from __DATE__/__TIME__,
    board name from BOARD_NAME; no hard-coded date or user line.
    - Help text bu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
2026-10-20 Fix M6 regression: rate-limit the fan PWM outside the PID
    The +/-25 PWM window was applied through QuickPID's output limits. With
    P on measurement those limits also clamp the running sum, so every D kick
    that hit the window edge was stored as a lasting PWM change and the loop
    oscillated (harness S3/S4/S8/S25 failed on the default plant).
    The PID output limits now stay at 0-255 and the rate limit acts on the
    fan PWM after Compute(), as before the M6 change.
    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
2026-10-20 Use clamp anti-windup in the PID (review finding 15)
    QuickPID 3.1.9's iAwCondition compares a one-sample step with the
    absolute output limits. It fires on most updates in which the airspeed
    rises, and then substitutes an iTerm that already contains -pmTerm before
    subtracting pmTerm again (QuickPID.cpp 100-112). With P on measurement
    this applies the P step twice and the I step times (1 + Ki x interval),
    so the loop is much more aggressive upwards than downwards.
    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
2026-10-20 Limit the PID's running sum to the PWM rate limit
    Follow-up to the M6 fix. Clipping only the fan PWM after Compute() lets
    QuickPID's running sum (integral plus P-on-measurement action) run ahead
    of the fan while it ramps. Now the sum itself may move at most
    MAX_PWM_CHANGE_PER_CYCLE per update (the excess is dropped, not stored),
    and the fan gets sum + D within the same rate limit. The limit is taken
    around the last sum, never around the fan PWM, so a clipped D kick is
    only delayed and cannot pile up in the sum (the original M6 mechanism).
    Why: with clamp anti-windup, the fan-only limiter and this one are equal
    on plants P0, P1, P3 and P4 (all pass), but on the fast plant P2 the
    fan-only lim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
2026-10-20 Use a fresh sTune object per run and check the e-stop in the wrapper
    sTune 2.4.0 leaves pvInst uninitialised and compares it with the
    emergency stop on the first Run(), so a run could abort at once with
    "pvInst > eStop" (harness S24). Its emergency-stop latch (eStopAbort) is
    never cleared, so after one trip every later run had no airspeed limit
    (review finding 4), and the wrapper never noticed a trip: the fan sat at
    the start PWM until the timeout.
    Each startTuning() now builds a new sTune object in zero-filled storage
    inside the wrapper. sTune's own e-stop is disabled (infinite limit); the
    wrapper checks the airspeed against the limit on every update() and
    returns ERROR, so the sketch stop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
2026-10-20 Start the sTune step from a running fan after a 25 s settle
    The step used to start from PWM 0 after a 5 s settle. The fan was often
    still running down from the PID target, and near 0 m/s the pitot signal
    is mostly noise, so sTune found a wrong dead time. The fan now holds
    0.6 x the step PWM for 25 s (long enough to settle from any earlier
    state, also from full speed) and then steps to the unchanged step PWM,
    so the peak airspeed does not change.
    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
2026-10-20 Convert sTune gains to QuickPID units and reject unusable results
    Review finding 16: sTune 2.4.0 reports Kp per unit of span (its process
    gain is normalised to the input and output spans, sTune.cpp line 194),
    GetKi() returns 1/Ti (line 429) and GetKd() returns 1/Td (line 452).
    QuickPID is parallel form in PWM and m/s, so the gains were applied
    about an order of magnitude too small. The wrapper now converts them in
    one place: Kp = Kp_span x outputSpan / inputSpan, Ki = Kp / Ti,
    Kd = Kp x Td. sTune's own summary (in its units) is turned off; the
    wrapper prints the process model (gain in m/s per PWM, dead time, tau)
    and the converted gains.
    Review finding 0: a step test without a clear respons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
2026-10-20 Shorten the sTune test time to 15 s
    Review finding 17: sTune's inflection-point model scales with the
    configured test time (its tangent window is 6 % of the samples), so with
    60 s the identified time constant was about 20 s on every plant.
    Measured with the harness S7 step test on the 5-plant grid (reference =
    tau1 + tau2 + 0.4 s averaging delay, sampling kept at 200 ms):
    test time worst tau error tuned loop oscillates on
    60 s +1071 % P2, P3
    30 s +510 % P2, P3
    20 s +317 % P2, P3
    15 s +171 % P2, P3
    10 s +108 % P1, P2, P3
    All runs completed. 10 s has the smallest worst-case error but
    und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
2026-10-20 Add safety checks: line timeout, airflow, dead sensor, airspeed limits
    Review findings 1, 2, 3, 5 and 20.
    - Serial: a partial line with no new character for 1 s now runs as a
    complete line, as with the original readStringUntil() timeout. With
    "No line ending" the stop command works again, and stale text is never
    prepended to a later command ("5", "0", "0\n" no longer gives 500).
    - No airflow (PID mode): if the fan has run at PWM >= 250 for 15 s in
    total since airflow was last measured, while the airspeed reads below
    1 m/s (pitot hose off, fan without power), the fan is stopped with an
    error. The time is added up rather than required in one piece, because
    near 0 m/s the noisy r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
2026-10-20 Fix platform issues: PWM frequency, LWLP bus, I2C pins, USB serial
    Review findings 7, 8, 9, 11, 13 and 14.
    - ESP32 fan PWM: attach the LEDC channel first (analogWrite 0), then set
    25 kHz on the attached pin. arduino-esp32 3.0.0-3.3.0 ignore
    analogWriteFrequency() on an unattached pin, so the fan ran at 1 kHz
    while the banner said 25000 Hz.
    - LWLP5000 on any bus: address 0x00 is probed on Wire, then on Wire1
    where the board has it (Uno R4 WiFi Qwiic), and the driver is created
    for the bus that ACKs. Boot prints the bus and halts with a clear error
    if none answers. New scanner helper probeDeviceBus().
    - ESP32-P4 I2C pins: -1 = the selected board's default SDA/SCL, so the
    M5Stack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
2026-10-20 Hand the relay tune over at the mean relay PWM
    Review finding 19: a relay tune always ends at a HIGH->LOW switch, so
    the PID started at the low relay PWM, below what the target needs, and
    the airspeed dipped after the hand-over. The fan is now set to the mean
    of the two relay levels (within the PWM rate limit) before the PID
    takes over. Harness S21, minimum true airspeed in the 10 s after the
    hand-over at SP 10: P0 8.97 -> 9.77, P2 8.55 -> 9.54, P3 9.37 -> 9.92 m/s.
    The rate-limited fan write is now one helper, setFanPwmRateLimited(),
    shared with the PID. The printed Ku and Tu are labelled as relay
    estimates; the hysteresis correction (finding 18) is not applied.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
2026-10-20 Update the sTan leak comment for the 75-sample sTune test
    The comment still gave the leak for 300 samples (72 bytes per run).
    With STUNE_SAMPLES = 75 the tangent buffer is 4 floats, 16 bytes per run.
    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
2026-10-20 Keep stop and safety checks working while serial output blocks
    Final review findings 1, 3 and 7.
    - 1: On a native USB port (Uno R4 Minima, ESP32 with USB CDC on boot)
    Serial.print() waits while the host does not read, which froze loop(),
    the stop command and the timeouts. serialHasRoom() (PlatformConfig.h)
    now gates all routine output: data lines, relay switch and cycle lines,
    sTune progress lines. Every stop, abort and safety path stops the fan
    before it prints; the sTune wrapper no longer prints when a run ends,
    the sketch calls printReport() once the fan is safe.
    - 3: The 1 s idle line timeout applies only until the first CR or LF;
    after that a pause while typing no longer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
2026-10-20 Stop a relay tune when no airflow is measured at the high level
    Final review finding 2. A pitot hose that comes off reads as "too slow",
    so the relay stayed at its high PWM (up to 255, beyond the sensor range)
    until the 120 s relay timeout. The PID-mode no-airflow check is now one
    helper, checkAirflow(fanDriven, fanState), used by both: in the relay
    tune the high level counts as driven, and after 15 s without airflow the
    tune is aborted with the fan stopped first.
    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
2026-10-20 Confirm every avg command and name the sTune step correctly
    Final review findings 4 and 6.
    - 4: "avg N" with the present N printed nothing. It now always prints the
    [CONFIG] confirmation; only the buffer reset is skipped when N is
    unchanged.
    - 6: sTune's outputStep is the PWM during the step, not its size. The
    doc comments say so and the start banner prints "Step: <start> ->
    <step> PWM".
    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
2026-10-20 Use 5-sample pressure averaging by default
    The 20-sample moving average (4 s window, 1.9 s mean delay) sits inside
    the control loop. In the host simulation it made the default gains
    (Kp 25, Ki 10, Kd 15) oscillate on 3 of 5 fan models; with 5 samples
    (0.4 s mean delay) the same gains were stable on 4 of 5. The user chose
    the shorter window as the default. 'avg <N>' still sets 1 to 50.
    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
2026-10-20 Correct the averaging comment
    The comment pointed to a fixed-PWM mode that does not exist. It now says
    what a longer window does: smoother readings, a slower loop, and a risk of
    oscillation that lower gains can offset.
    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
2026-10-20 Update and streamline the documentation; add PlatformIO and CI builds
    Docs, rewritten from the final firmware (facts sheet from code and real
    serial output, then a fact-check pass):
    - README.md: short entry page - supported boards, safety table, quick
    start, commands, serial output, configuration, troubleshooting,
    limitations. Each fact lives in one place; details link to the guides.
    - HARDWARE.md: ESP32-P4 and Uno R4 only; pins, fan wiring, level shifter,
    PWM pull-down advice, I2C wiring, M5Stack Tab5 pins, pitot plumbing.
    Mega, Giga and generic ESP32 content removed. (The four Mega/Giga wiring
    images were already deleted in e61e455; that commit staged them by
    mistake together w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
2026-10-20 Fix the Copilot review findings: sensor drift, bounded serial output
    - LWLP5000: the driver object is static again (was new). Its constructor
    sets only the bus, and begin() reads the drift member before it writes
    it. Heap memory is not zero-filled, so the first drift (and with it
    every later reading) could be wrong.
    - DATA_LINE_MAX_LENGTH 128 -> 160: the longest data line is 138
    characters with CR LF, so the old guard let the last bytes block.
    - New SerialOut (SerialOut.h/.cpp): all text output goes through it. On
    a native USB port it writes only what fits, waits for room only while
    the host reads, and after 50 ms without progress drops text until the
    host reads again; then it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
2026-10-21 Set the firmware version to 1.4
    Release 1.3 (tag DFRobot-Sensors) is the May 2026 code. The changes
    since then (safety checks, PID and auto-tune fixes, PlatformIO build)
    are version 1.4.
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2026-10-22 Set the firmware version to 1.4.1; fix the Known Issues link
    1.4.1 changes the default ESP32-P4 fan PWM pin to GPIO 4. The safety
    warning in the README linked to #limitations, which the section rename
    to "Known Issues" broke.
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
